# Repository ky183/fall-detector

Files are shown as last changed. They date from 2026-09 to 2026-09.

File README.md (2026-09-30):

# 智能跌倒检测报警器

清华大学第29届硬件设计大赛 · 民生赛道

面向**独居老人**的可穿戴跌倒检测报警器：手腕端采集姿态，腰部融合判断，跌倒时蜂鸣器报警 + OLED 显示 + 按钮取消 + WxPusher 微信推送。

## 当前状态（v0.6 · 2026-09-22，最终版）

- ✅ 全链路闭环（真机实测）：采集 → ESP-NOW(50Hz, ch6) → 三阶段触发 + 随机森林判决 → 报警/取消 → 按需 WiFi + WxPusher 推送
- ✅ v0.6 功能（详见 `docs/handover_2026-09-22_v0.6_ui_push_fix.md`）：
  - **腕端 OLED 产品化**：报警倒计时 / 已推送 / 已取消 / 正常页四级；调试布局由 `DEBUG_DISPLAY` 切换
  - **报警状态回显腰→腕**：`PKT_ACK` 单播，报警全程腕端同步显示
  - **步数统计（腕端纯本地）**：合加速度幅值（SVM）峰值检测 + 连续 4 步确认防误报，RAM 计数
  - **推送文案规范化** + **WiFi 重试卡死修复**（`cannot set config` 根因）+ 推送失败自动扫描诊断
- ⚠️ **两端固件须配套烧录 v0.6**（协议有变更，混搭不崩但腕端弹窗不出现）
- ⚠️ 复现注意事项：腰端供电 ≥6.65V（Micro USB 仅供烧录，否则蜂鸣器声弱）；演示前建议重启手机热点（偶发假死，见交接文档 §3.1）
- 终审答辩已完成（2026-09）

## 系统架构（双板 ESP-NOW）

| 端 | 硬件 | 职责 |
|----|---|---|
| 手腕 | XIAO ESP32S3（自制 PCB）+ MPU6500 + OLED + 按钮 + 电池 | 采集姿态 + 本地步数统计 + 报警回显显示 → ESP-NOW 发送 |
| 腰部 | ESP32-S3 + MPU6500 + 有源蜂鸣器 + EC11 编码器（取消） | 融合判断 + 两段式报警 + WiFi 推送 + 报警状态回传腕端 |

## 目录结构

```
├── firmware/               # 固件源码
│   ├── waist_firmware/     # 腰端固件（ESP32-S3 主控）
│   └── wrist_firmware/     # 腕端固件（XIAO ESP32S3）
├── algo/                   # 算法训练/评估/导出管线（离线，PC 上跑）
│   ├── 01_explore.py       #   随机森林主判决：探索→特征→训练→门限→导出
│   │   ... 05_export.py    #   产物 -> firmware/waist_firmware/rf_model.h
│   ├── sisfall.py          #   SisFall 数据集读取/预处理公共库
│   ├── cnn/                #   CNN 二级仲裁（FallAllD 数据集）
│   │   ├── cnn_train.py    #     训练 + 导出 firmware/.../cnn_weights.h
│   │   ├── host_replay/    #     双语言一致性回放（移植正确性的硬验收）
│   │   └── legacy/         #     接入前的原型（存档，不参与编译）
│   ├── data/               #   数据集（体积大，不入库，各自下载）
│   └── out/                #   训练报告 / 导出副本（留档）
├── docs/                   # 文档
│   ├── plan/               # 规划书、开发计划
│   ├── notes/              # 开发笔记、踩坑记录
│   └── defense/            # 答辩材料
├── hardware/               # 硬件资料
│   ├── schematic/          # 原理图
│   ├── pcb/                # PCB 文件
│   ├── enclosure/          # 3D 打印外壳
│   └── bom/                # 物料清单
├── bin/                    # 烧录文件（编译好的 .bin，交付物）
│   ├── waist/              # 腰端固件烧录文件
│   └── wrist/              # 腕端固件烧录文件
├── tools/                  # 工具脚本
│   └── check_consistency.py#   全项目静态一致性自检（不需硬件/数据集）
├── assets/                 # 演示素材（视频/图片）
└── test/                   # 测试记录
    └── logs/               # 测试日志
```

## 跌倒判定算法（两级判决）

| 级 | 模块 | 训练数据 | 何时跑 | 作用 |
|----|---|---|---|---|
| 第一级 · 主判决 | `fall_detector.cpp` + `rf_model.h` | SisFall 38 人 | 常态 50Hz | 冲击触发 → 特征 → 小随机森林 |
| 第二级 · 二级仲裁 | `cnn_detector.cpp` + `cnn_weights.h` | FallAllD 15 人 | **仅触发后 1 次** | 用腕端 6 通道补判 / 否决 |

- 第一级按"人"留出评估（5 个全新受试者，门限 0.40 部署点）：灵敏度 96.0% / 特异度 98.4%；老年组日常误报 4.6%。四方法完整对比（阈值法/大森林/小森林/混合门控）见 `docs/handover_2026-09-10_algo_v0.3.md` §2.2。
- 第二级只在“已触发 **且** 判定时腕端在线（仲裁窗覆盖率 ≥ `CNN_MIN_COVERAGE`）”时才跑一次；
  腕端离线或覆盖不足则视同不可信，**完全不跑**，行为回退到纯 RF（即已验收的 v2 路径）。
- 角色由 `config.h` 控制：`CNN_ROLE_RESCUE`（补漏报）/ `CNN_ROLE_VETO`（压误报）。
  两者当前均为 0，即影子模式（v0.4，2026-09-11）：CNN 照常推理并记录（decision
  日志的 `cnn p=` 行），但不改变判决结果。原因：CNN 按人评估的真实灵敏度为
  70~78%，低于 RF 主判决的 96%；需积累足够的佩戴对照数据并通过按人划分评估后，
  再决定是否授权其参与判决。
- 腕端链路一断，CNN 直接不跑；RF 主判决不依赖腕端 —— 失效开放（fail-open）设计。

### 改动算法后的验收

改完必跑，三道关都不需要硬件：

```bash
python tools/check_consistency.py       # ① 静态一致性：特征顺序/RF导出保真/板间协议/引脚
python algo/cnn/host_replay/replay.py   # ② 回放：需 g++，含算法保真/部署保真/固件集成（含报警全流程）
algo/05_export.py                       # ③ 随机森林离线指标（需 algo/data/ 数据集）
```

- ① 检查特征顺序、量程标度、两端 `protocol.h` 一致性等 22 项跨文件一致性问题
  （此类问题编译能通过、离线指标也无法暴露），全部通过时退出码为 0。
- ② 把 `firmware/` 下**真实的** `cnn_detector.cpp` / `fall_detector.cpp` /
  `alarm_manager.cpp` 等用 g++ 编到 PC 上跑，与一份独立写的 Python 参考实现
  逐条对比（判别不一致数必须为 0），并验证状态机、仲裁门控与报警全流程。
  数据集不在库时自动跳过「真实窗」项，不影响其余验收。

## 引脚分配

**腰端（ESP32-S3）**

| 功能 | 引脚 | 备注 |
|---|---|---|
| I2C SDA（MPU6500） | GPIO8 | 开漏，需上拉 |
| I2C SCL | GPIO9 | |
| 蜂鸣器（有源模块） | GPIO4 | 高电平=响；模块 VCC→5V；两段式节奏（取消窗内急促哔/推送后长鸣） |
| 按钮1（取消报警） | GPIO5 | 已实现 `PIN_BTN_CANCEL` |
| 按钮2（唤醒/自检） | GPIO6 | **预留**：config.h 尚未定义宏，功能未实现 |

**腕端（XIAO ESP32S3）**

| 功能 | 引脚 | 备注 |
|---|---|---|
| I2C SDA（MPU6500 + OLED） | D4（GPIO5） | 两者共用总线，100kHz |
| I2C SCL | D5（GPIO6） | |
| 交互按钮 | D2（GPIO3） | 短按=交互，长按=主动呼救（触发完整报警链路，联调时兼作模拟跌倒）；`PIN_BTN_1` |
| 电池 | BAT+ / BAT- 焊盘 | 不占 GPIO |

## 环境要求

- Arduino IDE 2.x
- ESP32 board package **3.x**（自带 XIAO_ESP32S3 板型，无需另装 Seeed 包）
- 库：Adafruit_GFX、Adafruit_SSD1306、Adafruit_BusIO、Adafruit_Sensor（MPU 为裸寄存器驱动，无需 MPU 库）

## 快速开始

1. 打开 `firmware/waist_firmware/waist_firmware.ino`，板子选 **ESP32S3 Dev Module**，烧录到腰端。
2. 打开 `firmware/wrist_firmware/wrist_firmware.ino`，板子选 **XIAO_ESP32S3**，烧录到腕端。
3. 串口波特率 `115200`。

## 开发计划

见 `docs/plan/` 与项目规划书（Step 0~7，两周）。

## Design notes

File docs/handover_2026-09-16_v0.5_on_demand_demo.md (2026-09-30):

# 交接文档 v0.5 收尾 —— 按需推送 + 演示/答辩准备（2026-09-16）

> 面向：全体组员（外形/算法/硬件分工均已到位，本文是"当前最后一公里"的交接）
> 前置阅读：`handover_2026-09-14_hw_integration.md`（接线表/交互规则/调参指南，仍然有效）
> 本文新增：①按需推送模式的来龙去脉 ②演示流程脚本 ③答辩要点 ④收尾待办

---

## 1. 本次改动内容（相对 09-14 交接）

### 1.1 推送改为"按需连接"模式（核心改动）

**背景**：常连模式（`PUSH_ALWAYS_ON=1`）下，腰端 WiFi 长期连着热点，射频必须跟随热点信道。
安卓热点会自动选"最空"的 2.4G 信道（1/6/11 三选一），手机不可控地漂移（实测 ch6→ch11）。
每次漂移 = 腰端射频跟着跑 ≠ 腕端 ESP-NOW 固定 ch6 → **腕端数据链路静默断流**（rx 不涨、LED 慢闪）。

**方案**（`config.h` → `PUSH_ALWAYS_ON=0`）：

| 阶段 | 行为 |
|---|---|
| 平时 | 不连 WiFi，腰端常驻 `ESPNOW_CHANNEL=6` 只收腕端包 |
| 报警确认后 | 连热点（超时 10s）→ WxPusher 推送 → 失败重试 6 次×15s |
| 推完/放弃 | `WiFi.disconnect()` + `esp_wifi_set_channel(6)` 跳回，腕端链路无感恢复 |

- **收益**：对任意信道的热点都鲁棒，不再要求信道对齐
- **代价**：微信收到时间 ≈ 7s 取消窗 + ~5s 连接 + ~4s 发送 ≈ **13~18s**（演示时提前打好招呼）
- 推送过程不影响蜂鸣器（已转入"长鸣"阶段持续响）

### 1.2 取消窗 10s → 7s

`ALARM_CANCEL_WINDOW_MS = 7000`。演示节奏更快。
**答辩被问"7 秒够吗"时**：量产定位建议 ≥8s（给老人留反应时间），下限 6s，7s 是演示权衡值（config.h 有注释）。

### 1.3 硬件集成批次（v0.5，commit `36c53e8`，已推送）

- 腕端状态 LED（`hw_led.h/.cpp`，GPIO8）：2s 心跳短闪=正常；1s 慢闪=链路故障（连续 10 次发送失败）；200ms 快闪=MPU 离线
- 腰端有源蜂鸣器两段式：取消窗内急促哔哔（300ms 响/500ms 周期）→ 推送后长鸣（800ms 响/1000ms 周期）
- EC11 编码器替代取消按钮：按压脚接 GPIO5（等效按钮，INPUT_PULLUP），旋转脚悬空
- 实测状态：板间通信 rx 正常涨、lost=0、lastAge 个位数 ms

### 1.4 待提交文件（git 状态截至 2026-09-16）

`36c53e8`（v0.5 硬件集成）已推送；工作区仅剩：
- `firmware/waist_firmware/config.h`（本文 §1.1/§1.2 的参数改动）
- `tools/wifi_test/wifi_test.ino`（调试期填了热点凭据；不想入库可先 `git checkout --` 还原占位符）

---

## 2. 系统现状一句话（答辩自我介绍用）

**腕端 XIAO ESP32S3 自制 PCB（MPU6500 50Hz）→ ESP-NOW 无线 → 腰端 ESP32-S3 大板三阶段触发 + 15 棵随机森林判决 → 两段式蜂鸣本地报警 → 7 秒可取消 → 微信远程推送（WxPusher）。**

### 2.1 核心指标（数据来源：SisFall 公开数据集，留出集按人划分，部署门限 0.40）

| 指标 | 数值 |
|---|---|
| 灵敏度（跌倒检出率） | **96.0%** |
| 特异度（日常活动不误报） | **98.4%** |
| 老年日常误报率 | 4.6% |
| CNN 二级仲裁（影子模式） | 真实灵敏度 70~78%，暂无判决权 |
| 板间链路 | 50Hz，正常时 lost=0 |

### 2.2 工程亮点（可当"创新点"讲）

1. **双传感源融合架构**：腕+腰两个位置独立采集，比单点方案信息量大（腕端否决票 v1 已预留：`ENABLE_WRIST_FUSION`，标定后开启）
2. **RF 主判决 + CNN 二级仲裁的保守架构**：CNN 不抢班夺权（RESCUE/VETO 影子模式跑对照数据），体现"可解释、可回退"的工程决策
3. **按需推送的射频共存设计**：单射频芯片上解决"ESP-NOW 固定信道 vs WiFi 热点信道漂移"的矛盾（§1.1，这是一个真实的工程问题）
4. **两段式报警 + 可取消**：先急促提醒本人（误报可按掉），7s 后才长鸣+推送叫家人——尊重老人尊严，避免"狼来了"
5. **训练域=部署域**：SisFall 200Hz→50Hz 降采样训练，与上板采样率一致；C++/Python 双语言回放 0 不一致

---

## 3. 演示流程脚本（答辩现场用）

**演示前 10 分钟准备**（缺一不可）：
- [ ] 腰端供电：≥6.65V（9V 适配器/PD 诱骗线；**5V 充电宝直连 Type-C 开不了机**）
- [ ] 手机热点开启，**停留在热点设置页面**（vivo"无设备连接自动关热点"高发；设置里关掉该选项更稳）
- [ ] 收推送的手机微信已关注 WxPusher 应用（历史收到过 code=1000 那台）
- [ ] 腕端开机后 LED 2s 心跳闪（若 1s 慢闪=链路故障，先重启腰端）

| 步骤 | 操作 | 观众看到 | 背后发生 |
|---|---|---|---|
| 1 | 双板上电，腰端静置 5s | 腕端 LED 心跳 | baseline 基线采集（`baseline tilt=xx, detector armed`） |
| 2 | 正常走两步、坐下起立 | 什么也不响 | 展示特异度（日常不误报） |
| 3 | **长按腕端按钮 1s**（模拟跌倒） | 蜂鸣器急促哔哔 | 三阶段触发→RF 判决→报警状态机 |
| 4 | **按一下编码器** | 蜂鸣停止 | 误报可取消（7s 取消窗） |
| 5 | 再次长按，这次**不取消** | 哔哔 7s → 转长鸣 | 推送任务连热点发 WxPusher |
| 6 | 举手机 | **微信收到"跌倒报警"** | ~13~18s 到达，提前说明 |
| 7 | （可选）贴串口日志 | rx 涨 lost=0 | 证明链路健康 |

**兜底**：提前录一遍完整流程的视频，现场设备出意外就放视频。

---

## 4. 收尾待办（按优先级）

| 优先级 | 事项 | 说明 |
|---|---|---|
| ★阻塞演示 | 腰端脱离电脑供电方案落地 | ≥6.65V：PD 诱骗线 / 9V 适配器 / 2S 18650 |
| ★阻塞演示 | 全流程彩排 ≥1 次 | §3 脚本跑通，掐表演述词 |
| ★阻塞演示 | 提交剩余改动并推送 | §1.4 两个文件 |
| 加分 | 佩戴测试协议 A/B + 调参 | 按 09-14 文档 §5，攒 decision 日志微调 `FD_RF_THRESHOLD` |
| 加分 | OLED 换新到货插 H1 座 | 当前模块烧毁，非阻塞（init FAIL 为预期） |
| 加分 | 腕端电池续航 ≥1h 验证 | 演示时长足够即可 |
| 加分 | 腰端洞洞板集成+腰包 | 消灭杜邦线，观感分 |
| 答辩材料 | PPT / 演示视频备份 | 建议含：系统架构图、指标表（§2.1）、双板实物照 |

---

## 5. 答辩 Q&A 备查

- **为什么用随机森林不用神经网络？** RF 在我们的数据上灵敏度 96% 显著优于 CNN v2 的 70~78%，且可解释、C++ 部署简单、推理开销可忽略。CNN 保留为二级仲裁（影子模式），攒数据后再授权——这是数据驱动的选择，不是能力问题。
- **数据集哪来的？** SisFall 公开数据集（含真跌倒+老年日常），按人划分防泄漏；200→50Hz 降采样保证训练域=部署域。
- **误报怎么办？** 三道防线：①特异度 98.4% ②7s 取消窗 ③腕端否决票（预留）。
- **老人没带手机 / 没网怎么办？** 本地蜂鸣器独立于网络；推送只是增项。
- **隐私？** 全部计算在设备端（边缘计算），不上云、不传原始数据，只发一条报警文本。
- **为什么双板？** 腰部姿态信息量大（跌倒=冲击+姿态剧变），腕部补充手臂动作；单点方案二者只能得其一。
- **信道漂移怎么解决的？** 见 §1.1，按需连接模式（实测发现热点漂移问题后采用的方案）。

---

## 6. 已知坑速查（现场应急）

| 症状 | 原因 | 处置 |
|---|---|---|
| 推送时 `WiFi connect timeout` | 热点被手机自动关了 / 手机连着别的 WiFi | 停留在热点设置页；关 WiFi 只留热点 |
| 腕端 LED 1s 慢闪 | 链路故障 | 重启腰端（信道被占/漂移残留） |
| 腰端 Type-C 供电不启动 | 电压 <6.65V | 换 ≥6.65V 供电 |
| 腕端插电池不亮 | （已修）BAT 飞线已补焊，SW2 已 P4 锡桥旁路 | 插电池=开机，无需开关 |
| OLED 不亮 | 模块烧毁待换 | 不影响主链路，忽略 |
| 烧录不上（腰端） | 用错 Type-C 当烧录口 | 烧录用 **Micro USB**（CH340） |

---

*文档生成：2026-09-16，随 v0.5 收尾批次维护。*

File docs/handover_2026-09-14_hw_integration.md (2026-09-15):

# 硬件集成交接文档 v0.5（2026-09-14）

> 写给组员（调参 / 外形设计 / 后续接手者）：硬件框架已全部打通并验收，
> 本文是**接线位置、交互规则、调参入口**的唯一速查。看完即可动手，不必考古聊天记录。
> 配套：算法细节见 `handover_2026-09-10_algo_v0.3.md`（RF 主判决）与
> `handover_2026-09-11_cnn_v2.md`（CNN 影子模式）。

## 0. 一句话状态

双板全链路（采集 → ESP-NOW → 三阶段触发 + 随机森林判决 → 蜂鸣器两段式报警
→ 编码器取消 → WiFi 常连 → 微信推送）已在实物上验收通过；
剩余工作集中在**跌倒判定参数调优**（本档 §5）与外壳/佩戴形态。

## 1. 系统总览

```
腕端 XIAO ESP32S3（自制PCB）          腰端 ESP32-S3 大板（面包板/杜邦线）
  MPU6500#1 + 按钮 + LED + 电池         MPU6500#2 + 有源蜂鸣器 + EC11编码器
  （OLED 座已留，屏坏待换）             + WiFi 常连 → WxPusher 微信推送
        └────── ESP-NOW 50Hz ch6 ──────┘   （信道必须=热点信道，见 §7）
```

## 2. 接线速查表（★ = 外形设计可挪，见 §6）

### 2.1 腕端（自制 PCB，引脚由 PCB 走线决定，**不可软件改位**）

| 功能 | 位号 | 丝印 | GPIO | 可否挪 |
|---|---|---|---|---|
| I2C SDA（MPU+OLED） | — | D4 | 5 | ❌ PCB 定死 |
| I2C SCL | — | D5 | 6 | ❌ |
| 按钮 SW3 / 外接口 P3 | SW3 | D2 | 3 | ❌ |
| 状态 LED1 | LED1 | D9 | 8 | ❌ |
| OLED 座（屏待换） | H1 | — | I2C | ❌ |
| 电池链路 | U12→SW2→P5→飞线→XIAO底面BAT焊盘 | — | — | ❌ |
| 空闲扩展脚 | 排母 | D0/D3/D7/D8 | 1/4/44/7 | ✅ 可接新外设 |

### 2.2 腰端（大板 H4 排针，杜邦线连接，**随时可挪**）

| 功能 | 大板脚 | GPIO | 模块侧 |
|---|---|---|---|
| MPU#2 SDA ★ | H4 第12脚 | 8 | SDA |
| MPU#2 SCL ★ | H4 第15脚 | 9 | SCL |
| MPU#2 电源 ★ | 3V3 / GND | — | VCC / GND |
| 蜂鸣器 I/O ★ | H4 第4脚 | 4 | I/O（高电平响） |
| 蜂鸣器电源 ★ | 3V3（或5V）/ GND | — | VCC / GND（宽压3.3~5V） |
| 编码器按压脚 ★ | H4 第5脚 | 5 | 两脚无方向（按压导通） |
| 编码器另一脚 ★ | GND | — | 旋转脚 A/B/COM 全悬空 |
| 烧录+供电 | Micro USB（CH340口） | — | 电脑（板选见 §8） |

## 3. 交互规则（谁按什么发生什么）

| 操作 | 位置 | 效果 |
|---|---|---|
| **长按 1 秒** | 腕端按钮 SW3 | 模拟跌倒（联调专用）：腰端直接触发报警流程 |
| 短按 | 腕端按钮 | 预留交互（OLED 翻页 TODO，现无动作） |
| **按压一下** | 腰端编码器 | **取消报警**并复位系统（仅报警态有效） |

**报警状态机**（触发后自动流转，10s / 推送两个节点）：

```
触发(真摔或长按模拟)
  → [0~10s 取消窗] 蜂鸣器急促哔哔(0.3响/0.2停) —— 按编码器 → 全停+复位
  → [10s 到] 自动连WiFi推送微信 → 蜂鸣器转长鸣(0.8响/0.2停) —— 按编码器 → 停+复位
  → 复位后需站直5s重新采基线（串口 detector armed）
```

**腕端 LED 闪法**：每2s短闪=一切正常；每秒闪=链路故障(腰端没开/信道不对)；
快速闪=MPU 离线。

**使用纪律（不是 bug，摘戴会伪触发）**：先佩戴→再上电；关机→再摘下；
MPU 板面平贴腰前。

## 4. 串口日志速查（调参看什么）

- `[STAT] rx=N lost=N lastAge=Nms`：链路健康，lost 涨=丢包
- `[DETC] decision proba=0.47 peak=78.5 tilt=1deg gyr=500 wrist=11.2/cov98% (3501ms)`：
  **核心行**。proba≥0.4 判跌倒报警；wrist/cov=腕端数据健康度
- `cnn p=0.xx`：CNN 影子记录（**不参与判决**，攒对照数据用，勿据此调参）
- `detector armed`：基线完成，开始判定

## 5. 调参指南（唯一需要动的文件：`waist_firmware/config.h`）

| 参数 | 现值 | 方向 | 效果 |
|---|---|---|---|
| `FD_TRIGGER_SVM` | 30 m/s² | ↓更易触发 | 冲击门限（≈3.1g） |
| `FD_TRIGGER_GYR` | 200 °/s | ↓更易触发 | 旋转门限（与SVM满足其一） |
| `FD_RF_THRESHOLD` | 0.40 | ↓更灵敏、误报升 | **判决门限，主调项**（0.3/0.4/0.5 档见算法交接文档 §2.2） |
| `FD_BASELINE_MS` | 5000 | 一般不动 | 开机站姿基线时长 |
| `FD_COLLECT_MS` | 3500 | 一般不动 | 触发后确认窗 |
| `ALARM_CANCEL_WINDOW_MS` | 10000 | 不建议<6000 | 取消窗 |

**调参方法**：改宏 → 烧腰端 → 按下表协议做动作 → 存档所有 decision 行：

- 协议 A（阴性，要求零报警）：走30s / 快坐×3 / 跳×3 / 弯腰×3 / 下蹲×3
- 协议 B（阳性，要求≥7/9 报警）：垫上侧摔/前扑/后倒各×3，每轮取消后站直5s

误报多 → `FD_RF_THRESHOLD` 上调；漏检多 → 下调 SVM/阈值。改完记录在
`test/logs/`（文件名建议 `param_<日期>_<阈值>.txt`）。

## 6. 外形设计者：改 GPIO 位置的规则

- **腰端随便挪**：杜邦线换到别的 GPIO + 改 `waist_firmware/config.h` 对应宏
  （`PIN_I2C_SDA/SCL/PIN_BUZZER/PIN_BTN_CANCEL`）→ 重烧即生效。
  唯一注意：I2C 两根建议用默认 I2C 脚（8/9），其他脚需软件 Wire 兼容。
- **腕端不能挪**：引脚由 PCB 走线焊死，挪=飞线。需要新传感器/外设时
  用 §2.1 的空闲扩展脚（D0/D3/D7/D8），固件里加宏即可。
- 外壳开孔参考 `腕端PCB交接文档_v1.md` §8（USB-C/OLED窗/SW3/SW2/表带通道）。
  腰端建议腰包方案（蜂鸣器出声、编码器可按、USB 可插）。

## 7. 已知事项与坑（2026-09-14 快照）

1. **OLED 模块已损坏**（PCB 首插疑似错位烧毁），已购新待换；
   无屏不影响任何功能，`OLED init FAIL` 日志为预期
2. **腕端 SW2 电源开关虚焊失效**，已用 P4 焊盘锡桥旁路：
   插电池=开机，拔电池=关机；充电照常（USB 插线）
3. **腰端供电**：桌面调试 Micro USB 即可；**脱离电脑演示必须 ≥6.65V**
   （PD 诱骗线/9V 适配器/2S 电池），5V 充电宝带不动 WiFi
4. **热点信道约束**：手机热点须 2.4G 且实际信道=6（=ESPNOW_CHANNEL）；
   失配串口有 `!!` 告警。换热点先看 `WiFi connected ... ch=X`
5. 推送期间 ESP-NOW 丢包短暂暴涨属正常（WiFi 借射频），推完自恢复
6. `secrets.h` 不入库：新环境复制 `secrets.h.example` 填 WiFi/WxPusher

## 8. 烧录速查

| 端 | 板型 | 关键选项 | 口 |
|---|---|---|---|
| 腰端 | ESP32S3 Dev Module | USB CDC on Boot=**Disabled** | Micro USB |
| 腕端 | XIAO_ESP32S3 | 默认 | 板载 Type-C |

串口均 115200。改任何算法相关文件后跑 `python tools/check_consistency.py`（22 项自检）。

---
*本档对应提交：v0.5 硬件集成。文档与代码同库，发现不符以代码为准并更新本档。*

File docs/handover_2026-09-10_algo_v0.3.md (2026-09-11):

# 交接文档 — 2026-09-10 · 算法上板 v0.3

> 写给后续开发者（人或 AI）：本文档记录截至 2026-09-10 晚的项目全貌。
> 阅读顺序建议：§1 现状 → §3 已验证/未验证 → §4 当前阻塞 → §6 待办。
> 代码内的权威注释：`fall_detector.cpp` 头部有"训练↔固件对应关系表"，改任何一侧先看它。

## 0. 一句话状态

跌倒判定算法已完成"离线训练 → C++ 移植 → 上板运行 → 微信推送"全链路；
腰端已在真机上跑通判定与推送；**当前阻塞在硬件层（供电 ≥6.65V 未落实）**，
佩戴测试与腕端融合标定未开始。

## 1. 系统当前形态

```
腕端 XIAO ESP32S3 ──ESP-NOW 50Hz ch6──> 腰端 ESP32-S3 大板
  MPU6500(±8g/±500°/s)                   MPU6500#2 + 蜂鸣器 + 取消按钮 + WiFi
  OLED + 按钮(长按=模拟跌倒)              ├ 三阶段触发 + 15树随机森林判定
  （腕端只发原始数据，不做判定）           ├ 报警状态机(10s取消窗) → WxPusher微信
                                         └ WiFi常连模式(与ESP-NOW同信道共存)
```

| 模块 | 状态 | 说明 |
|---|---|---|
| 双板采集 + ESP-NOW | ✅ 稳定 | 常连共存下丢包 ~7%，lastAge 稳定个位数 ms |
| 腰端判定算法 | ✅ 已上板 | 详见 §2 |
| 报警/取消/推送 | ✅ 实测通过 | 摔倒→微信 ~17s（3.5s判定+10s取消窗+4s POST）|
| 腕端融合 v1 | ⚠️ 代码就绪未验证 | `ENABLE_WRIST_FUSION=0`，等待腕端链路+自采数据标定 |
| 佩戴测试 | ❌ 未开始 | 弹力腰带未到货 |
| 供电 | ❌ **阻塞** | 大板需 ≥6.65V，详见 §4 |

## 2. 算法部分（algo/ 目录）

### 2.1 数据集与管线

- 数据集：**SisFall**（38 人 / 4505 文件 / 1798 次跌倒，腰部佩戴，200Hz）
  - 下载位置：`algo/data/sisfall/`（gitignore，组员自行下载）
  - 下载方式：HuggingFace 镜像 `hf-mirror.com/datasets/Trupal7/Sisfall_Dataset`
    （直连 hf.co 被墙；zip 232MB，解压后即 SisFall_dataset 目录）
- 管线脚本（按序号执行，各带 `check` 自检模式）：
  1. `sisfall.py` — 加载器：位值→物理单位、200→50Hz 块平均降采样（=固件采样率，
     训练域=部署域）、姿态角（低通 IIR α=0.03，与固件同参）
  2. `01_explore.py` — 可视化证明"三阶段判决缺一不可"（答辩素材 `out/explore.png`）
  3. `02_features.py` — **触发锚定**特征提取（不是全文件滑窗，防泄漏），12 特征，
     5920 样本。v2 关键点：**量程裁剪 CLIP_ACC=±8g / CLIP_GYR=±500°/s**（数据集
     传感器 ±16g/±2000°/s，不裁剪则模型学到硬件达不到的规则，上板失效）
  4. `03_train.py` — 训练+严格评估（见 2.2）
  5. `04_threshold.py` — 阈值基线 + 四方法对比 + 参数标定（只在训练集标定）
  6. `05_export.py` — 训练 15树小森林 → 生成 `firmware/waist_firmware/rf_model.h`
     （自动生成勿手改）+ **双语言一致性回放**（C 遍历逻辑的 Python 镜像 vs sklearn，
     5920 样本判决 0 不一致才允许上板）

### 2.2 关键指标（答辩数字，全部来自"模型没见过的人"）

| 方法 | 留出集灵敏 | 留出集特异 | 老年日常误报 | SE06老人真摔检出 |
|---|---|---|---|---|
| 阈值法（三阶段AND） | 72.8% | 99.3% | 3.8% | 76.0% |
| 随机森林 300 树 | 97.9% | 97.9% | 6.7% | 88.0% |
| **小随机森林 15树×深6（上板方案）** | **97.1%** | **97.5%** | 6.9% | 89.3% |
| 小森林@门限0.4（部署点） | 96.0% | 98.4% | 4.6% | 85.3% |

- 评估方法论（答辩重点）：按"人"划分（SA04/09/14/19/23 留出）；老年组不进训练、
  专门做泛化压力测试；阈值参数只在训练集标定后冻结
- 已知弱点（诚实记录）：坐姿晕倒型跌倒（F13/F14/F15）漏报集中；体重最轻受试者
  的"软摔"漏报；改进思路是自适应基线，评估为高风险暂缓

### 2.3 上板实现（腰端固件）

- `fall_detector.cpp`：状态机 BASELINE(开机站5s采基线)→IDLE(触发: SVM>30 或
  |ω|>200)→COLLECT(3.5s确认窗)→判决→LATCHED(锁存到报警取消)。特征窗口定义
  与训练侧逐条对应（注释里有对照表）
- `rf_model.h`：1083 节点 ≈17KB 常量，15 树遍历
- 判决日志格式：
  `[DETC] decision proba=0.47 peak=78.5 tilt=1deg gyr=500 wrist=11.2/cov98% (3501ms)`
  （wrist 字段无论融合开关都输出，是标定融合阈值的数据来源）

## 3. 已验证 vs 未验证（接手必读）

**已在真机验证：**
- 判定→报警→取消→微信推送全链路（多次，含 code=1000 成功回执）
- WiFi 常连 + ESP-NOW 同信道共存（POST 期间 rx 仍增长）
- 判定管线"正确拒绝"能力（强冲击+无姿态变化 → proba=0.07 拒绝）

**未验证（下次继续的点）：**
1. **腕端数据进判决日志**：实测时腕端链路已死，`wrist=-1.0/cov0%`。
   验证标准：腕端开机+链路正常时，decision 行出现 `wrist=9~12/cov>90%`
2. 佩戴状态下的完整测试协议（A 阴性/B 阳性，见下）
3. 融合否决票的实际效果（阈值是工程初值，需自采数据标定）

## 4. 当前头号问题：供电（未解决，其他问题的疑似总根源）

**大板输入必须 ≥6.65V**（板载 DC-DC 最小输入；5V 充电宝实测带不动 WiFi）。
2026-09-10 晚出现的一组症状统一指向供电不稳：
- 无人触碰时 SVM 恒 ~41 m/s²（4.2g 假读数）反复触发
- MPU 反复 offline（时间点与 WiFi 活动窗重合）
- WiFi 连接失败、腕端链路大量丢包

**待办**：PD 诱骗线（充电宝→9V→DC5521，10~20元）或 9V/12V DC 适配器。
换正规供电后第一步：静置观察 SVM 是否回到 ~9.8、trigger 风暴是否消失。
（腕端 XIAO 无此问题，5V USB 正常。）

## 5. 已知设计内行为与使用纪律（不是 bug，答辩可能被问）

1. **摘戴/摆弄装置 = 伪跌倒信号**（姿态大变+静止）。纪律：先佩戴→再上电；
   先关机→再摘下。误触发有 10s 取消窗兜底。腕端否决票正式启用后可拦大部分
2. **MPU 朝向**：绝对朝向无所谓（基线相对），但推荐板面平贴腰前（与 SisFall
   训练一致）。上电后改变朝向会被视为跌倒
3. **基线假设开机站立**：报警取消后会重新采基线，需站直 5 秒等 `detector armed`
4. 推送时间线 ~17s，可调 `ALARM_CANCEL_WINDOW_MS`（不建议低于 6s）

## 6. 待办清单（优先级）

1. 【阻塞】解决供电（PD 诱骗线/适配器）→ 复测 SVM 稳定性
2. MPU 四焊点补焊（VCC/GND/SDA/SCL）+ 杜邦线固定（佩戴装备到货前的常规加固）
3. 腕端链路验证（§3.1 的标准）
4. 佩戴装备到货 → 测试协议：
   - A 阴性：走30s/快坐×3/跳×3/弯腰×3/下蹲×3，合格=零报警（decision proba<0.4 允许）
   - B 阳性：垫上侧摔/前扑/后倒 ×3，合格=≥7/9 报警；每轮取消后站直5s
   - 记录所有 decision 行（proba + wrist 值）= 第一批自采标定数据
5. 用自采数据标定融合阈值 → `ENABLE_WRIST_FUSION=1`
6. 数据采集工具（腕腰两端 DEBUG_DATA CSV 输出）→ 域差距量化
7. （可选）"自愈检测"创新点、第二数据集交叉验证、起跳类特征增强

## 7. 新环境复现指南（组员从零跑通）

```powershell
git clone https://github.com/ky183/fall-detector.git
cd fall-detector
# 数据集（232MB，需 Python: numpy/pandas/scipy/matplotlib/scikit-learn）
#   从 hf-mirror.com/datasets/Trupal7/Sisfall_Dataset 下载 zip
#   解压到 algo/data/sisfall/SisFall_dataset
python algo\02_features.py check     # 自检
python algo\02_features.py all       # 全量特征（~2分钟）
python algo\03_train.py              # 训练+评估报告
python algo\05_export.py             # 重新生成 rf_model.h + 一致性回放
# 固件：Arduino IDE 打开 firmware/waist_firmware（板: ESP32S3 Dev Module,
#   USB CDC on Boot=Disabled, 烧录口 Micro USB），secrets.h 照
#   secrets.h.example 填。腰端供电必须 ≥6.65V！
```

## 8. 关键参数速查（全部在腰端 config.h，有注释）

| 参数 | 值 | 含义 |
|---|---|---|
| ESPNOW_CHANNEL | 6 | 两端一致；常连模式下还须=热点信道（失配有串口告警）|
| FD_TRIGGER_SVM / GYR | 30 m/s² / 200°/s | 冲击触发（满足其一）|
| FD_RF_THRESHOLD | 0.40 | 森林判决门限（部署点指标见 §2.2）|
| FD_BASELINE_MS / COLLECT_MS | 5000 / 3500 | 基线时长 / 确认窗时长 |
| ENABLE_WRIST_FUSION | 0 | 腕端否决票（标定后开）|
| FUSION_VETO_* | 0.6 / 30 / 12 | 覆盖率/腰端强冲击/腕端安静阈值 |
| PUSH_ALWAYS_ON | 1 | WiFi 常连模式（0=按需连接）|
| PUSH_MAX_ATTEMPTS | 6 | 推送重试 6 次×15s，不再丢弃 |
| ALARM_CANCEL_WINDOW_MS | 10000 | 报警取消窗 |

## 9. 文件索引

| 路径 | 内容 |
|---|---|
| `algo/` | 离线管线（§2.1），`data/`和`reference/`已gitignore |
| `firmware/waist_firmware/rf_model.h` | 森林常量表（05_export.py 生成）|
| `firmware/waist_firmware/fall_detector.*` | 判定算法（头注释=对应关系表）|
| `firmware/waist_firmware/net_pusher.cpp` | 推送（常连/按需双模式）|
| `algo/out/train_report.txt` | 训练评估报告留档 |
| `tools/` | i2c_scanner / btn_test / wifi_test 排障工具 |
| `docs/notes/mpu6500_driver_note.md` | MPU6500 驱动踩坑记录 |

---
*v0.3 tag：`git tag -a v0.3`（若提交时遗漏）。文档随代码一起 commit。*

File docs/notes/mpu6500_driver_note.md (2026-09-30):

# 踩坑记录：MPU 模块实为 MPU6500，更换裸寄存器驱动

> 日期：2026-09-06 · 记录人：组长 · 影响范围：腕端/腰端传感器层

## 现象

- 腕端固件持续打印 `[SENS] MPU offline, retrying...`，SVM 显示 0
- I2C 扫描器能扫到 0x68（器件"在线"）
- Adafruit_MPU6050 库的 `begin()` 始终失败

## 排查过程（供复用）

1. I2C 扫描器确认器件地址在线 → 排除接线问题
2. 换第二个模块、换杜邦线、量上拉电压（SDA 对 GND ≈3.3V）→ 排除硬件损坏
3. 加诊断日志直接读 WHO_AM_I 寄存器（0x75）→ **读出 0x70**
4. 结论：模块实际是 **MPU6500**（WHO_AM_I=0x70），而非 MPU6050（0x68）
5. Adafruit_MPU6050 库严格校验芯片 ID=0x68，故拒绝初始化——这就是
   "扫描器通、固件不通"的根因

期间还发现并修复了另外两个独立问题（同一次排障中）：

- XIAO 排针焊点虚焊（D5 对 GND 电压异常，补焊解决）
- I2C 400kHz 时钟在补焊总线上不稳（降回默认 100kHz，50Hz 采样带宽足够）

## 解决方案

`firmware/wrist_firmware/sensor_manager.cpp` 改为**裸寄存器驱动**：

- 直接读写 MPU 寄存器（唤醒 0x6B、量程 0x1B/0x1C、滤波 0x1A、数据 0x3B 连读 14 字节）
- 芯片 ID 宽容校验：接受 0x68/0x70/0x71 等（6050/6500/6515 全系）
- 不再依赖 Adafruit_MPU6050 库（该库其他功能仍在，只是本驱动不使用）
- 腰端 MPU 驱动直接复用这份实现

## MPU6500 vs MPU6050 性能影响

| 项 | MPU6050 | MPU6500 | 对本项目影响 |
|----|---|---|---|
| 加速度计 | 16bit，同类设计 | 基本相同 | 无 |
| 陀螺仪噪声 | 0.005 °/s/√Hz | ≈0.0037 °/s/√Hz | 6500 略优 |
| 量程/分辨率/采样率 | 16bit，±2~16g | 相同配置可用 | 无 |
| 寄存器/数据格式 | 基准 | 兼容 | 无（裸驱动已验证） |

**结论：对跌倒检测（SVM 阈值 + 角速度特征）无实质影响，陀螺噪声甚至略低。**
算法组按原计划标定即可，无需针对型号调整。本问题可作为"问题定位与解决"的案例引用。

## 经验

1. 廉价 GY 系模块芯片型号与商品名不符很常见，遇"库不识别"先读 WHO_AM_I
2. I2C 排障顺序：扫描器（地址在不在）→ 读 ID（芯片是什么）→ 时序（降速试）
3. 自焊开发板排针必须逐点测通断，"灯亮"只代表供电脚焊好了

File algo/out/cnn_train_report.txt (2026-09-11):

================================================================
CNN 二级仲裁 v2 训练报告（smoke=False, seed=42, epochs=50）
划分: 按受试者留出 ['1', '14', '5']；标签: 峰值锚定；增广: rot=0.5 drop=0.25 mask=0.25
================================================================

---- 模型 A：随机旋转增广（默认导出版） ----
 thr   TP   FN   FP   TN    sens    spec
 0.5   29   11    4 1042   0.725   0.996
 0.6   29   11    4 1042   0.725   0.996
 0.7   28   12    3 1043   0.700   0.997
 0.8   27   13    2 1044   0.675   0.998
 0.9   26   14    2 1044   0.650   0.998
逐人（thr=0.8）:
  1: sens=0.789 spec=1.000 (TP15 FN4 FP0 TN302)
  14: sens=0.000 spec=1.000 (TP0 FN0 FP0 TN351)
  5: sens=0.571 spec=0.995 (TP12 FN9 FP2 TN391)
腕端30%丢包鲁棒性(thr=0.8): sens=0.700 spec=0.992

---- 模型 B：无旋转增广（ablation 对照） ----
 thr   TP   FN   FP   TN    sens    spec
 0.5   31    9    9 1037   0.775   0.991
 0.6   31    9    9 1037   0.775   0.991
 0.7   31    9    8 1038   0.775   0.992
 0.8   31    9    8 1038   0.775   0.992
 0.9   31    9    7 1039   0.775   0.993
逐人（thr=0.8）:
  1: sens=0.842 spec=0.993 (TP16 FN3 FP2 TN300)
  14: sens=0.000 spec=0.997 (TP0 FN0 FP1 TN350)
  5: sens=0.714 spec=0.987 (TP15 FN6 FP5 TN388)
腕端30%丢包鲁棒性(thr=0.8): sens=0.900 spec=0.990

判读：A 对 B 若 sens/spec 均无明显下降，则旋转增广换来佩戴朝向鲁棒性是纯收益；若明显下降，重新评估旋转策略（如限幅小角度）后再定导出版。

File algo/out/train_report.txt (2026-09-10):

== 留出集（5 个全新青年受试者） ==
   灵敏度 Sensitivity =  95.5%  (358/375 跌倒被检出)
   特异度 Specificity =  99.9%  (误报 1/682)
   精确率 Precision   =  99.7%

== 误报的动作明细（top） ==
   D11: 1/25 次误判

== 漏报的跌倒明细 ==
act subject trial
F13    SA04   R02
F13    SA09   R02
F15    SA09   R01
F15    SA09   R03
F01    SA14   R02
F06    SA14   R03
F09    SA14   R05
F05    SA23   R01
F05    SA23   R02
F05    SA23   R03
F05    SA23   R04
F05    SA23   R05
F13    SA23   R01
F13    SA23   R03
F15    SA23   R02
F15    SA23   R03
F15    SA23   R04

== 特征重要度（应与物理直觉一致） ==
   gmag_peak_imp    0.272 ###########################
   svm_peak_imp     0.206 ####################
   svm_impulse_imp  0.132 #############
   dtilt_med_post   0.105 ##########
   svm_std_post     0.062 ######
   dtilt_max_post   0.061 ######
   dtilt_chg        0.045 ####
   svm_dip_pre      0.036 ###
   svm_mean_pre     0.023 ##
   gmag_std_post    0.022 ##
   dip_dur_pre      0.022 ##
   svm_mean_post    0.016 #

== 老年组压力测试（训练只见青年，测老人日常动作） ==
   老年日常误报 29/951 = 3.0%（SisFall 论文预期：明显差于青年，属正常现象）
   D11: 11 次
   D08: 9 次
   D14: 5 次
   D10: 2 次
   D17: 1 次
   SE06(柔道专家)真实跌倒检出 62/75 —— 老人跌倒能否检出，比误报更关键

== 5 折按人交叉验证（训练集内部，看稳定性） ==
   Sensitivity 97.3% ± 1.6
   Specificity 98.0% ± 0.7

== 判决门限 sweep（灵敏度 vs 特异度 trade-off） ==
      th   sens%   spec%
     0.3    97.9    97.9
     0.4    97.1    98.8
     0.5    95.5    99.9
     0.6    92.8    99.9
     0.7    89.1    99.9
   （部署原则：宁可灵敏，误报有人工取消窗口兜底）

========== 04_threshold 追加 ==========
== 阈值参数（仅用训练集标定，已冻结） ==
   T1 冲击峰值    > 30 m/s²  (3.1g)
   T2 角速度峰值  > 200 °/s
   T3 姿态变化    > 20 °
   T4 冲击后活动  < 6 m/s²
   训练集得分 (SE+SP)/2 = 86.4%

== 四种方法对比（留出集=5 个全新青年受试者） ==
   方法                灵敏%    特异%   误报    老年FP%   SE06检%
   A 阈值法            72.8   99.3    5      3.8     76.0
   B 随机森林300        97.9   97.9   14      6.7     88.0
   C 小随机森林15x6      97.1   97.5   17      6.9     89.3
   D 混合门控           96.0   97.9   14      6.6     82.7

决策依据（第⑥步 C++ 移植选型）：
    - 若 C 小森林 ≈ B 大森林 -> 用 C（数组化移植体积可控）
    - 若 C 明显掉点且 D 占优 -> 上板走 D（阈值粗筛 + 精简 ML）
    - 阈值法 A 是保底与参照系，也是"两代方法对比"报告章节的数据来源

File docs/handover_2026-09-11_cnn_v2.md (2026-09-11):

# CNN 二级仲裁 v2 交接文档（v0.4，2026-09-11）

> 写给算法组：本文说明对 CNN 二级仲裁（commit `e23f5d5`，下称 v1）的审阅结论、
> 本轮全部改动、理由与验证结果。改动仅涉及**训练侧与一个固件开关**，
> 你的板端实现（cnn_detector.cpp / cnn_detector.h / host_replay）一行未动。
> 复核指引见 §8，全部结论可用仓库内工具一键复现。

## 0. 一句话摘要

v1 的板端移植质量过硬（双语言回放 0 不一致），但训练侧有三处方法论问题
（窗口泄漏 / trial 级标签 / 无域增广），导致其指标虚高、且不可直接部署。
本轮重写训练脚本（v2）并以**影子模式**上板：RF 仍独自主判，CNN 只记录
不生效，等佩戴测试攒够对照数据后再决定是否授权。

## 1. 对 v1 的审阅结论（已当面/文档反馈过，此处留档）

**保留不动的部分**（这些做得很好）：
- 腰腕 12 通道输入设计与"二级仲裁只看腕端增量信息"的定位
- 归一化换算链（LSB 往返）与文件头文档 —— 实测量化过错法代价，可信
- 全部工作缓冲 static 化（避开 18KB 栈溢出）
- host_replay 三层验收 + check_consistency 静态自检 —— 本轮全部复用

**发现的问题**（均为训练侧，板端无 bug）：
1. 随机窗口划分：50% 重叠的相邻窗口横跨训练/测试两侧 -> 指标虚高
2. trial 级标签：摔前站立、摔后躺卧的窗口也被标为"跌倒" -> 错误语义
3. 无部署域增广：训练数据腕端从不缺失、轴向固定，与实机（丢包 + 佩戴
   朝向不可控）存在两个未对齐的域差

## 2. 改动清单与理由

### 2.1 firmware/waist_firmware/config.h —— 影子模式（1 行）

`CNN_ROLE_RESCUE` 1 -> 0。

- **影响**：CNN 照常计算并记录（decision 日志的 `cnn p=` 行不变），
  但不再能把 RF 未判跌倒的事件补判为报警。行为回退到纯 RF（= 已验证的 v2 主判决）。
- **理由**：v2 重训后的真实灵敏度约 70~78%（RF 为 96%），在"RF 漏掉的
  子集"上的表现未测过，不应有改变判决的权力。
- **开启条件**：佩戴测试攒出"RF 对/错 × CNN p 高/低"对照表且分布达标后。

### 2.2 algo/cnn/cnn_train.py —— 重写为 v2

| 修复 | 实现 | 理由 |
|---|---|---|
| 按受试者划分 | 每 5 人留出 1 人（本次 1/5/14），jitter 副本只进训练侧 | 消除窗口泄漏，测试集全是训练没见过的人 |
| 峰值锚定标签 | 正样本=腰端 SVM 峰值居中 2s 窗（与板端 cnn_detector_prob 取窗同构）；摔前(-6,-4s)/摔后(+4,+6s)补负样本 | 标签语义改为"窗口内正在跌倒"，且训练/部署取窗方式一致 |
| 腕端缺失增广 | 25% 整窗置 0 + 25% 随机 30% 拍置 0 | 板端 cov<1 的窗口里有 0 值，原属域外输入 |
| 随机旋转增广 | 腰/腕各自独立随机 SO(3)，同端 acc/gyr 同一旋转矩阵（保手性） | 腕端 PCB 佩戴朝向不可控 + 数据集轴向无从核对，迫使模型学朝向无关特征 |
| ablation | 旋转开/关各训一版对比，导出旋转版 | 项目纪律：不让性能无谓变差，用数据取舍 |

归一化常量与导出格式与 v1 逐字一致，**板端无需任何改动**。
新增 `--smoke`（合成数据验流程）、`--no-rot`、`--epochs` 参数。

### 2.3 firmware/waist_firmware/cnn_weights.h —— 重新导出

v2 旋转增广版权重（6210 float，规模不变）。由 2.2 的脚本自动生成。

### 2.4 新增 algo/cnn/inspect_data.py —— 数据体检工具

训练前的数据可信度检查（标度 / SMOTE 痕迹 / 腕陀螺来源 / 零填充），
答辩复现用。本次对 FallAllD 处理版 pkl 的体检结论见 §3。

## 3. 数据体检结论（FallAllD_40SamplesPerSec_ActivityIdsFiltered.pkl）

来源核实为 Kaggle "Derived FallAllD Dataset"（CC0）。四个关键结论：

1. **标度精确成立**：腰端静止段 |acc| 中位数换算后 = 1.00g（50 分位），
   证实 4096 LSB/g 假设；与板端 ±8g/±500dps 换算链完全对齐
2. **腕端陀螺是真实独立通道**（与腰部相关系数仅 0.19，非复制非填充）
3. **未发现 SMOTE 合成样本**（索引连续、无重复键）——Kaggle 数据卡片
   声明的 SMOTE 只在上传者自己的 notebook 里，未写入 pkl
4. trial 统一 800 点（20s）为截断而非填充（尾部零值占比 0%）

结论：该 pkl 可直接用于训练；原始版 FallAllD.pkl（462MB）留作后备。

## 4. v2 训练结果（真实、无泄漏）

数据：3875 窗（正 370 / 负 3505），留出受试者 1/5/14，seed=42，50 epochs。
完整报告见 `algo/out/cnn_train_report.txt`。

| 测试条件 | A 旋转增广（已导出） | B 无旋转（对照） |
|---|---|---|
| 原始轴向 | sens 67.5% / spec 99.8% | sens 70.0% / spec 98.8% |
| **随机旋转（模拟腕端乱戴）** | **sens 77.5% / spec 98.7%** | sens 92.5% / **spec 77.7%（崩）** |
| 旋转 + 30% 丢包 | sens 77.5% / spec 97.8% | spec 74.1%（崩） |

- B 的 sens 升高是"整体倾向报跌倒"的假象（伴随 spec 崩盘证实）；
  其判据依赖轴向信息，轴向一变行为不可控
- **A 在全部条件下 spec ≥ 97.8%，是任意佩戴朝向下唯一可信的版本**
- 真实灵敏度 70~78% vs RF 主判决 96% —— 影子模式的直接依据

## 5. 本轮明确没有动的部分

- cnn_detector.cpp / cnn_detector.h / cnn_weights.h 的板端实现逻辑
- host_replay/ 全部、tools/check_consistency.py、RF 管线（algo/01..05）
- 腕端固件（protocol.h 两端仍逐字节一致）
- 板端归一化换算、窗口/抽取逻辑

## 6. 已验证 / 未验证

**已验证**（本机一键复现，见 §8）：
- check_consistency 22/22 通过（特征序、RF float32 保真、量程标度链等）
- host_replay：Test A 双语言 0 不一致；Test B（本机有 pkl 后首次运行）
  24 真实窗全路径（单位换算→50Hz→抽取）概率偏差 0、跨 0.80 门限翻转 0 个
- Test C 两级判决集成回放通过（含影子模式下的行为）
- v2 训练全流程（smoke + 真数据各一遍）

**未验证**（待实机）：
- 真人佩戴下 CNN p 值的实际分布（影子数据未开始收集）
- RESCUE/VETO 的开启决策（依赖上一条）
- CNN 灵敏度提升空间：正样本仅 370 窗（每 trial 1 正窗 + 1 jitter 副本），
  下轮可增加 jitter 副本数至 3~4 个/受试者试验再对比

## 7. 后续路线（按优先级）

1. 烧录腰端（本版 v0.4，影子模式）→ 正常佩戴测试，串口日志留存
2. 影子数据攒够后统计 2×2 表 → 决定 RESCUE（补漏报）/ VETO（压误报，
   A 的 spec 99.8% 在此方向有潜力）及门限
3. （可选）正样本扩充重训；老年组压测（需确认 pkl 受试者年龄构成）

## 8. 组员复核指引（约 5 分钟）

```bash
python tools/check_consistency.py          # 应 22/22 PASS
python algo/cnn/host_replay/replay.py      # 应 [PASS]，Test B 需本机有 pkl
python algo/cnn/cnn_train.py --smoke       # 应全流程跑通（不落产物）
```

重点复核 `algo/cnn/cnn_train.py` 的 `build_windows()`（锚定切窗）与
`augment_batch()`（旋转/缺失增广）两函数——v2 与 v1 的全部实质差异都在
这两处与划分逻辑。有异议欢迎在分支上改动后开 PR，训练侧脚本与固件
已解耦（归一化口径不变），互不阻塞。

## 9. 环境与数据备忘

- 本机（腰端开发机）已装 TensorFlow 2.21（CPU 版），pkl 位于 algo/data/
  （.gitignore 排除，不入库）；E 盘另存一份原始版 FallAllD.pkl 备查
- cnn_model.h5（v2 旋转版）与训练报告首次入库于 algo/out/，便于复现

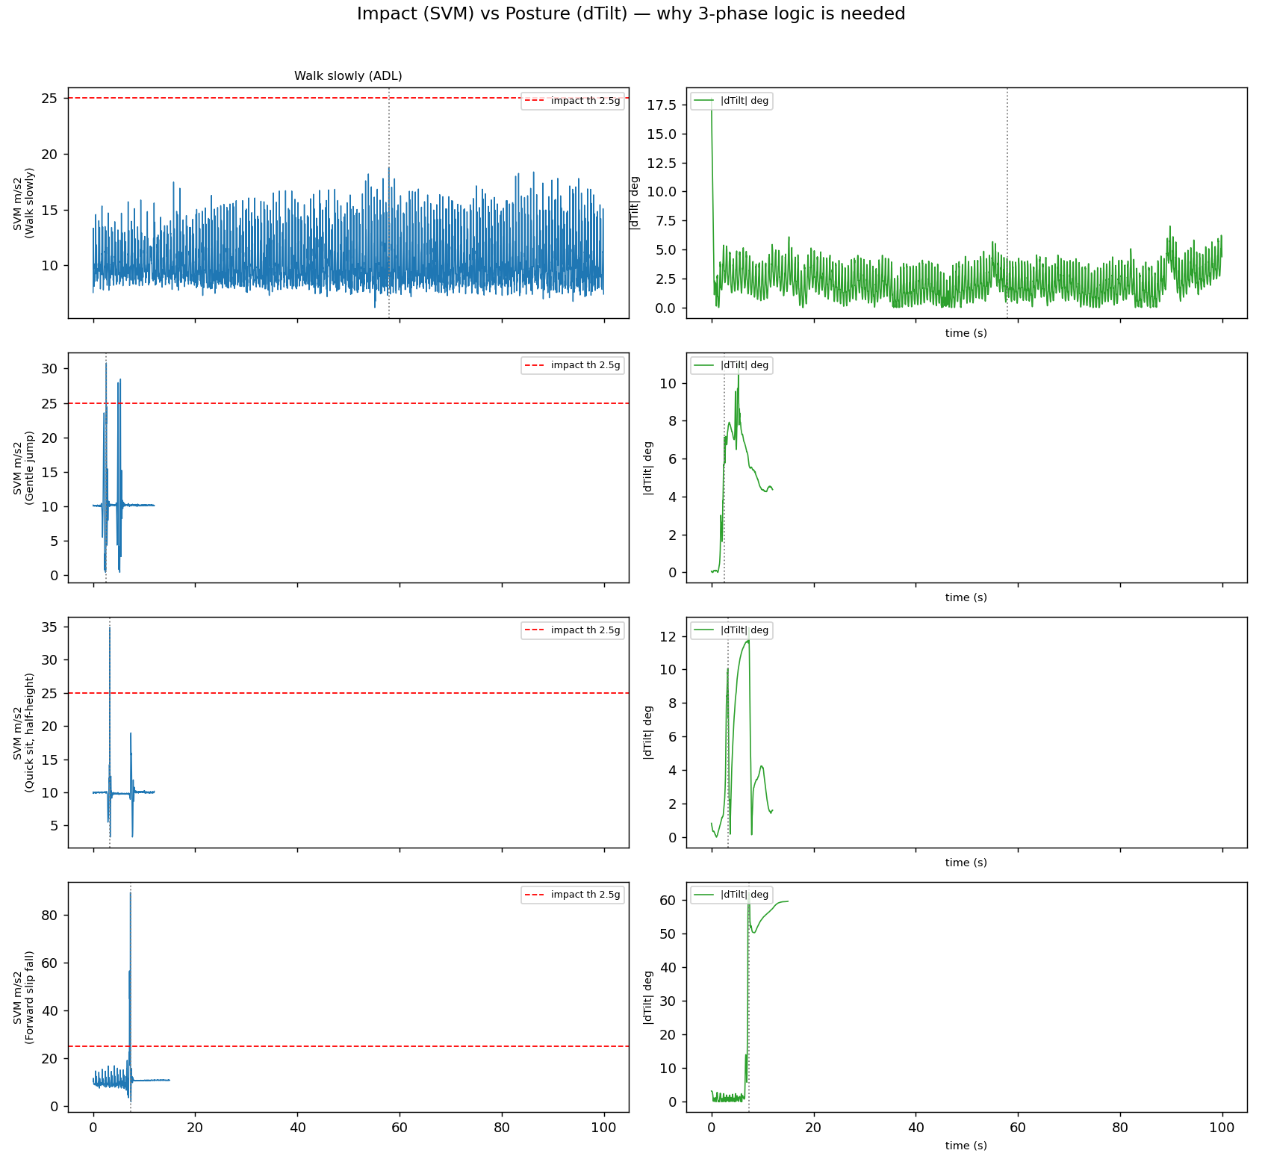
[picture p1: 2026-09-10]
algo/out/explore.png

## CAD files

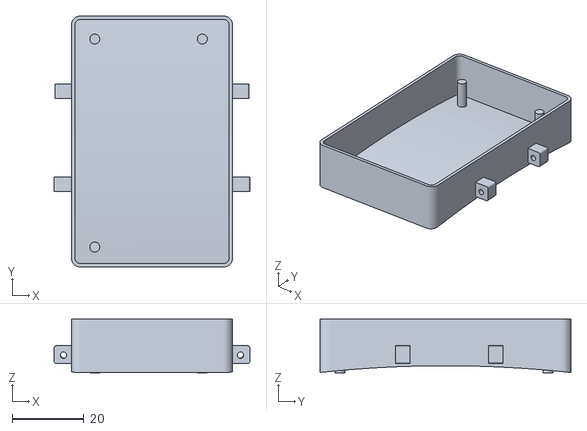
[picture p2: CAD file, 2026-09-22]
hardware/enclosure/腕端最终.stl
54.5 x 70.0 x 15.0

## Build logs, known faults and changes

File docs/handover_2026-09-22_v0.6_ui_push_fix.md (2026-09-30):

# 交接文档 v0.6 —— 产品化 UI + 报警回显 + 步数统计 + 推送加固（2026-09-22）

> 面向：全体组员（v0.6 功能包交接）
> 前置阅读：`handover_2026-09-16_v0.5_on_demand_demo.md`（按需推送/演示脚本，仍然有效）
> 开发分支：`feature/v0.6-ui`（自 `v0.5` tag 起，共 11 个提交）
> 核心原则：**只做旁路改动**——`fall_detector` / `alarm_manager` 状态机 / 采样发送主链路零修改

---

## 1. 本次改动内容（相对 v0.5）

### 1.1 推送文案规范化（腰端 `config.h` 三个宏）

| 项 | 新文案 |
|---|---|
| 消息标题 | `【跌倒报警】请及时关注` |
| 正文 | `【跌倒报警】设备检测到疑似跌倒，7 秒内未按取消键，已确认报警。请尽快联系老人确认状况。` |

只改宏字符串，`net_pusher.cpp` 的拼包逻辑零改动。

### 1.2 报警状态回显：腰→腕 `PKT_ACK`（新通信方向）

协议里预留的 `PKT_ACK`（type=0x03）正式启用，载荷 `AckPayload{alarmState, remainSec}`（2 字节，包大小不变仍 38B）：

- **腰端**（`net_espnow.cpp` 新增 `espnow_send_ack()`）：报警状态变化立即发；取消窗内 2Hz 重发；推送后 1Hz 重发。目标 MAC 取自首个收到的腕端数据包（自动缓存 + add peer，无需配置）。开关 `ENABLE_ALARM_ECHO`（置 0 = 射频行为回到 v0.5）。
- **腕端**（`net_espnow.cpp` 新增接收回调，原本只发不收）：只处理 `PKT_ACK`，只写 4 个 volatile 变量，不碰采样/发送。

### 1.3 腕端 OLED 四级页面（产品化 UI）

优先级从高到低（`ui_oled.cpp`）：

| 页面 | 触发 | 内容 |
|---|---|---|
| 报警弹窗 | alarmState=WAIT | `! FALL DETECTED !` 反色条 + 剩余秒**大字倒计时 7→1** + `WAIST KNOB=CANCEL` |
| 已推送页 | alarmState=SENT | `! FAMILY ALERTED !` + `NOTIFYING VIA WECHAT` |
| 已取消页 | 收到 NORMAL（3 秒） | `CANCELLED` + `FALSE ALARM` |
| 正常页 | 默认 | 运行时长大字 + `STEPS n` + `LINK: OK` |

- **正常页布局开关 `DEBUG_DISPLAY`**（腕端 `config.h`）：0=产品布局（上述）；1=原调试布局（SVM 大字+事件计数）。调试能力保留，一改宏即回。
- 显示滞后 ≤0.5s（OLED 500ms 刷新周期）；推送连 WiFi 期间腕端弹窗可能短暂停在旧状态（信道被占用，推完自动恢复）——均为设计内行为。
- 演示脚本 P17 口径：长按 **1 秒**（`BTN_LONG_PRESS_MS=1000`，中途试过 2s 又按演示需求改回）。

### 1.4 步数统计（腕端纯本地，新模块 `pedometer.h/.cpp`）

- **架构决策：腕端本地算**——本机 50Hz SVM 直接喂入，本地计数、本地 OLED 显示。零通信改动、零协议改动、腰端零依赖。定位：腕端从"只采集转发"升级为"数据本地产出健康指标"。
- 算法（规则法，不训练模型）：动态幅值 `|SVM−9.81|` → EMA 低通（α=0.2）→ 阈值 2.0 m/s² 过阈记候选峰 → 迟滞回差（阈值一半）防抖 → 两峰间隔窗 250~2000ms。
- **两级防误报**：① 阈值挡日常小幅动作；② **连续 4 步确认**——孤立晃动（1~3 峰）不计数，连续走出第 4 步时把前几步一起补记；停走 >2s 重新确认。与报警取消窗同一设计哲学："宁可多一道确认，不做不可靠判定"。
- 存储为 RAM（重启清零）——调试期决策；日后要持久化加 NVS 低频落盘（每小时+每千步）即可，接口已预留 `pedometer_reset()`。
- 调参法（写进 config 注释）：`DEBUG_DISPLAY=1` 走路看 SVM 峰值，阈值 ≈ 峰值动态幅值 × 0.7。**最终调参建议按实际佩戴方式标定**（手持与绑腕数值差异大）。开关 `ENABLE_PEDOMETER`。

### 1.5 WiFi 推送加固（★重要 bug 修复，与时间功能无关）

**修复：推送重试卡死**。原 `connect_wait` 连接超时后不做清理，STA 芯片仍在后台重试连接，15 秒后的下一次 `WiFi.begin()` 被拒（串口铁证：`wifi:sta is connecting, cannot set config`），6 次重试全部假失败。修复：`WiFi.begin` 前先 `WiFi.disconnect()` 清残留 + 超时路径终止后台连接。**此缺陷 v0.2 起就存在，只是"热点先开"的演示流程从未触发过**——任何"第一次连接失败再重试"场景（热点晚开、信号弱）都会踩中，v0.5 同样受影响，属净收益修复。

**新增：失败自动扫描诊断**。推送连接超时后自动全信道扫描 2~4 秒，打印：扫到的 AP 总数、目标热点（信道/信号/加密方式）或"目标不在广播"。本次排查中它一锤定音地区分了"固件问题"与"热点侧问题"（见 §3.1）。

### 1.6 已移除：NTP 时间同步（做过、验证过、主动撤掉）

曾实现"腰端开机一次性 NTP → epoch 经 PKT_ACK 下发 → 腕端走时显示真实时钟"全链路（含失败重试、报警避让），联调中被手机热点问题干扰（见 §3.1），按"推送可靠性优先"原则主动移除。**实现完整封存于 git 历史 `d337728`~`1c87b4f`，恢复直接 cherry-pick**。若日后重启此功能，推荐改用"腰端推送成功时顺手 NTP（复用已建立的 WiFi 连接，零新增射频窗口）+ 时间存 NVS 断电保持"，或腕端低频自连（腕端连 WiFi 期间腰端算法自动回退本地 MPU 判定，安全性已有兜底）。

---

## 2. 烧录与兼容须知

- **v0.6 两端固件必须配套烧录**（协议 `AckPayload` 启用）。混搭不会崩溃（v0.5 腕端会忽略 ACK 包），但弹窗/取消页不出现。
- 版本号：两端 setup 串口打印 `v0.6` 可核对。
- 编译环境不变（Arduino IDE 2.x + ESP32 3.x），无新增库依赖。

## 3. 调试/演示注意事项（实测记录）

### 3.1 手机热点"假死"

现象：热点开关显示"开着"，但 ESP32 扫描全信道找不到它（`diag: TARGET AP NOT in air`），任何设备都连不上；**重启热点立即恢复**。伴随已知问题：安卓"无设备连接自动关热点"（vivo 高发，演示 Checklist 已有预警）。

**演示前固定动作**：① 关闭"无设备连接自动关闭热点"选项；② **上电前重启一次手机热点**（重启即排假死，比"检查开着"可靠）；③ 停留在热点设置页面。

### 3.2 腰端供电与蜂鸣器（待最终确认）

蜂鸣器报警变为"很小的哒哒声"——最大嫌疑是**用 Micro USB（烧录口）长期供电**（5V 且电流弱，蜂鸣器拉电流时电压跌落）。诊断树：换 Type-C/DC ≥6.65V 供电触发报警 → 仍小则蜂鸣器直连 3.3V/5V 测本体 → 本体坏换备件（有第二个）。**演示 Checklist 的"≥6.65V 供电"一条是硬性的。**

### 3.3 lost 计数口径

`lost` 是累计值不回零。WiFi 连接/扫描期间（报警推送、诊断扫描）腕端数据必然断流几十到几百包——属设计内。**看增量不看绝对值**：射频空闲期 lost 增量应为 0。

### 3.4 演示新可展示点

- 报警时腕端 OLED 弹窗+大字倒计时（报警全程腕端有画面）
- 取消后腕端 `CANCELLED` 页
- 正常页 `STEPS`：现场走几步数字跳（连续 4 步起跳，晃一下不涨——可当小互动）

## 4. 已知问题与遗留

| 项 | 状态 | 下一步 |
|---|---|---|
| 蜂鸣器哒哒声 | 疑似供电不足（Micro USB） | 按 §3.2 诊断树确认；演示时用 ≥6.65V |
| 步数灵敏度 | 阈值 2.0（手持标定，近似值） | 按实际佩戴方式依 §1.4 标定法复调 |
| 腰端按钮2（GPIO6） | 预留未实现 | 暂不实现 |
| 时间显示 | 已移除 | 不恢复；恢复路径见 §1.6 |
| 09-14 交接文档遗留 | 已全部完成 | — |

## 5. Git 提交清单与合并（截至本文档提交）

```
b6cc80e feat: 推送文案规范化
b8089ff feat: 报警状态回显(PKT_ACK) + 腕端产品化UI（弹窗/倒计时/取消页，DEBUG_DISPLAY）
d337728 feat: 腕端时钟显示            ┐
82f221f feat: NTP提速+避让            │ 时间功能（已移除，
82b1918 fix:  WiFi重试卡死修复        │ 实现封存于此段历史，
1c87b4f chore: 暂关NTP+推送诊断       │ cherry-pick 可恢复）
435842e diag:  扫描列出全部AP         ┘
8ac5392 revert: 移除NTP时间功能（保留修复与诊断）
6bff15e feat: 腕端步数统计（纯本地）
4f75ac0 fix:  步数防误报（阈值+连续4步确认）
740ef09 fix:  步数阈值回落2.0
```

合并到 main 并打 tag（主开发机执行）：

```bash
git checkout main
git merge feature/v0.6-ui
git tag -a v0.6 -m "v0.6: 产品化UI + 报警回显 + 步数统计 + 推送加固"
git push origin main --tags
git branch -d feature/v0.6-ui
```

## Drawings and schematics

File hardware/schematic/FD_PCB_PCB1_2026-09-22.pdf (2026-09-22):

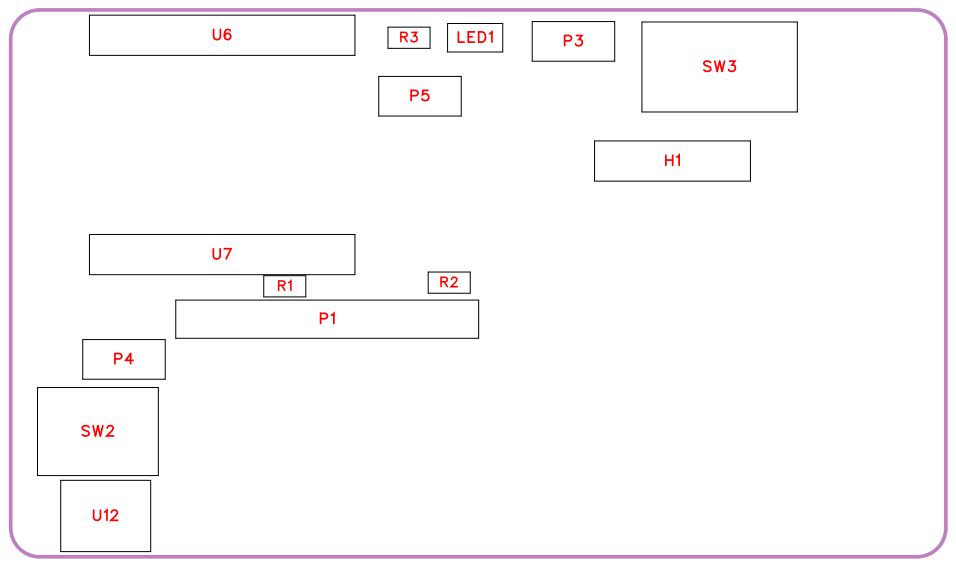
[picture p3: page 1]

No. | Quantity | Comment | Designator | Footprint | Value | Manufacturer Part | Manufacturer | Supplier Part | Supplier
1 | 1 | 2.54-1*4P 母 | H1 | HDR-TH_4P-P2.54-V-F | | 2.54-1*4P 母 | BOOMELE( ) 博穆精密 | C2718488 | LCSC
2 | 1 | 150060YS75 000 | LED1 | LED0603-R-RD_YELLO W | | 150060YS75 000 | | C990001228 6 | LCSC
3 | 1 | 2.54-1*8P 母 环保 | P1 | HDR-TH_8P-P2.54-V-F | | 2.54-1*8P 母 环保 | BOOMELE( ) 博穆精密 | C27438 | LCSC
4 | 1 | J7 BTN外接 | P3 | HDR-TH_2P-P2.54-V-F | | J7 BTN外接 | BOOMELE( 博穆精密 ) | C49661 | LCSC
5 | 1 | J8 开关旁路 | P4 | HDR-TH_2P-P2.54-V-F | | J8 开关旁路 | BOOMELE( 博穆精密 ) | C49661 | LCSC
6 | 1 | J10 BAT引线 | P5 | HDR-TH_2P-P2.54-V-F | | J10 BAT引线 | BOOMELE( 博穆精密 ) | C49661 | LCSC
7 | 2 | 4.7k | R1,R2 | R0603 | 4.7k | 0603WAF47 01T5E | UNI-ROYAL( ) 厚声 | C23162 | LCSC
8 | 1 | 1k | R3 | R0603 | 1k | RC0603FR-0 71KL | YAGEO(国巨 ) | C22548 | LCSC
9 | 1 | MSK-12C02-1_5Hgge12 | SW2 | SW-TH_MSK 12C02 | | SW2 滑动 | | C990001830 5 | LCSC
10 | 1 | SW1 | SW3 | KEY-SMD_4 P-L6.0-W6.0-P4.50-LS8.6 _H8.5 | | SW1 轻触 | Megastar( 兆 星 ) | C7470159 | LCSC
11 | 1 | J1 XIAO 座 A | U6 | HDR-TH_7P-P2.54-V-M-1 | | J1 XIAO 座 A | | C990003449 7 | LCSC
12 | 1 | J2 XIAO B 座 | U7 | HDR-TH_7P-P2.54-V-M-1 | | J2 XIAO B 座 | | C990003449 7 | LCSC
13 | 1 | J9 电池座 | U12 | CONN-TH_2 P-P2.00_BO SSIE_BX-PH 2.0-2PZZ | | J9 电池座 | | C990009516 2 | LCSC

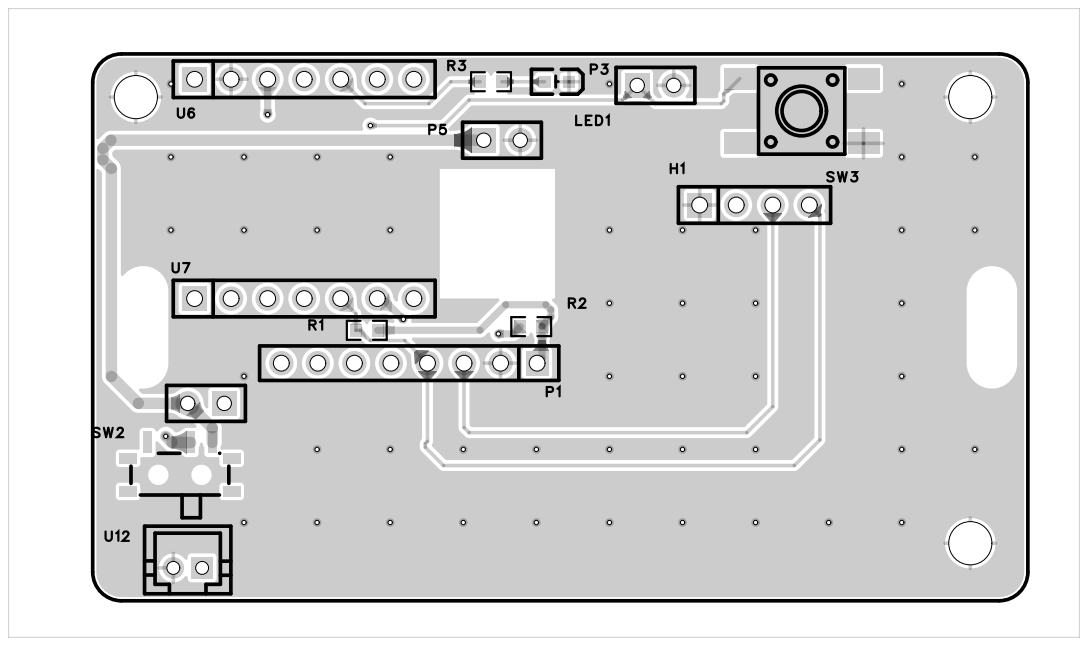
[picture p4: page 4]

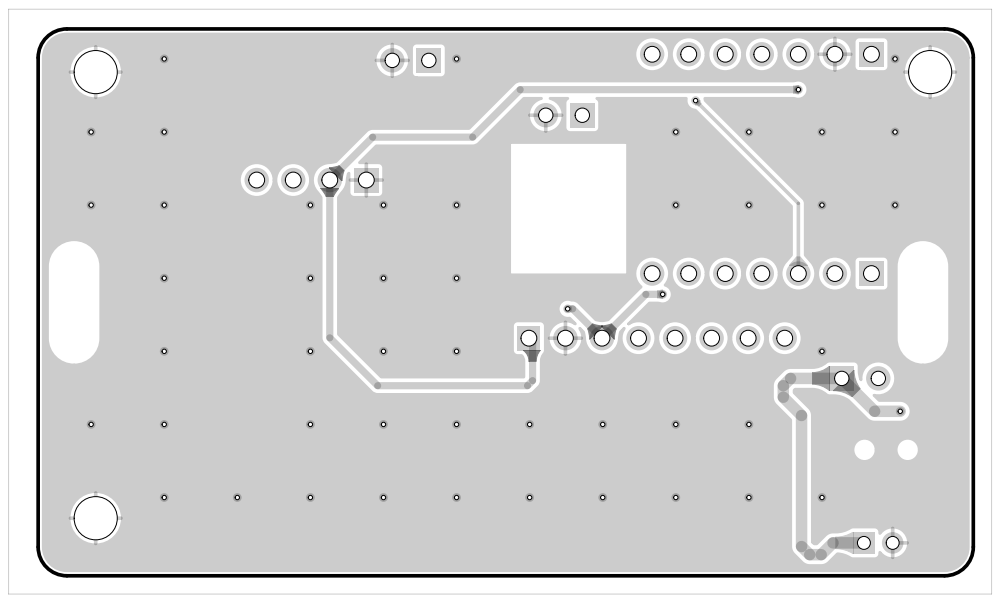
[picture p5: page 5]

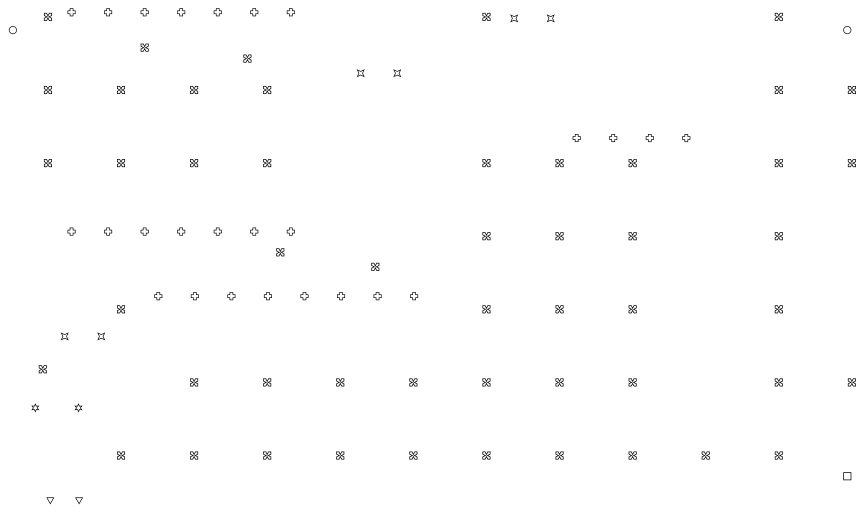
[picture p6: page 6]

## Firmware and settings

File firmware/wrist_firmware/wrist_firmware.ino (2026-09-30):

// ============================================================
//  腕端固件入口 — XIAO ESP32S3
//  智能跌倒检测报警器 · 清华第29届硬件设计大赛
//  职责：采集姿态 → OLED 显示 → ESP-NOW 发送 → 腰端
//
//  任务一览（FreeRTOS，全部跑在 core1，WiFi 协议栈在 core0）：
//    task_sensor   50Hz  高   读 MPU → 写共享数据 g_sensor_data（含步数统计）
//    task_tx       50Hz  高   读共享数据 → ESP-NOW 发送
//    task_button   20Hz  中   按钮扫描（去抖+短/长按）
//    task_led      20Hz  低   状态 LED 步进闪烁
//    task_display   2Hz  低   OLED 刷新
//
//  跌倒判定不在腕端：ENABLE_FALL_DETECT=0 时长按按钮发"模拟跌倒"
//  命令给腰端，触发完整报警链路（主动呼救 / 联调模拟共用）
// ============================================================
#include "config.h"
#include "logger.h"
#include "protocol.h"
#include "sensor_manager.h"
#include "ui_oled.h"
#include "ui_button.h"
#include "hw_led.h"
#include "pedometer.h"
#include "net_espnow.h"
#include <Wire.h>
#include <freertos/FreeRTOS.h>
#include <freertos/task.h>

// ================= 运行状态（display/日志共用） =================
static volatile uint32_t g_evt_cnt   = 0;   // 按钮事件累计
static volatile uint32_t g_sim_until = 0;   // 模拟跌倒提示截止时刻（OLED 显示用）

// ================= 任务实现 =================

// 传感器采样：严格 50Hz（vTaskDelayUntil 保证周期稳定，不累积误差）
static void task_sensor(void* pv) {
    TickType_t last = xTaskGetTickCount();
    const TickType_t period = pdMS_TO_TICKS(1000 / SAMPLE_HZ);
    for (;;) {
        vTaskDelayUntil(&last, period);
        bool ok = sensor_manager_read();
        led_report_mpu(ok);              // LED 快闪 = MPU 离线
#if ENABLE_PEDOMETER
        // 步数统计：读成功后取共享快照喂入（锁内纯计算，耗时纳秒级）
        if (ok && xSemaphoreTake(g_sensor_mutex, pdMS_TO_TICKS(10))) {
            pedometer_feed(g_sensor_data.svm);
            xSemaphoreGive(g_sensor_mutex);
        }
#endif
        if (!ok) {
            // MPU 离线（read 内部已重试），降频打印避免刷屏
            static uint32_t lastErr = 0;
            if (millis() - lastErr > 1000) {
                LOG_E("SENS", "MPU offline, retrying...");
                lastErr = millis();
            }
        }
    }
}

// 无线发送：复制一份共享数据快照再打包（持锁时间最短化）
static void task_tx(void* pv) {
    TickType_t last = xTaskGetTickCount();
    const TickType_t period = pdMS_TO_TICKS(1000 / SAMPLE_HZ);
    for (;;) {
        vTaskDelayUntil(&last, period);
        SensorData snap;
        if (xSemaphoreTake(g_sensor_mutex, pdMS_TO_TICKS(10))) {
            snap = g_sensor_data;
            xSemaphoreGive(g_sensor_mutex);
        } else {
            continue;   // 偶发拿不到锁：跳过本帧，不阻塞任务
        }
        espnow_send_data(snap);
        led_report_tx(g_espnow_last_ok);   // LED 慢闪 = 连续发送失败（链路故障）
    }
}

// 状态 LED：50ms 步进闪烁状态机（闪烁含义见 hw_led.h）
static void task_led(void* pv) {
    for (;;) {
        vTaskDelay(pdMS_TO_TICKS(50));
        led_tick();
    }
}

// 按钮扫描：短按=交互（翻页 TODO），长按=主动呼救（联调时兼作模拟跌倒）
static void task_button(void* pv) {
    for (;;) {
        vTaskDelay(pdMS_TO_TICKS(BUTTON_POLL_MS));
        ButtonEvent e = button_poll();
        if (e == BTN_NONE) continue;

        g_evt_cnt++;
        if (e == BTN_SHORT) {
            LOG_I("BTN", "short press (evt=%lu)", (unsigned long)g_evt_cnt);
            // TODO(交互)：OLED 多页显示时在此切换页面
        } else {  // BTN_LONG
            LOG_I("BTN", "long press -> SIM FALL");
#if ENABLE_FALL_DETECT
            // 算法启用后，模拟功能关闭（避免干扰真实判定）
            LOG_I("BTN", "fall detect enabled, sim ignored");
#else
            espnow_send_cmd(CMD_SIM_FALL);
            g_sim_until = millis() + 3000;   // OLED 提示 3 秒
#endif
        }
    }
}

// OLED 刷新：组装 UiInfo → 刷新（慢速低优先级，绝不干扰采样）
static void task_display(void* pv) {
    for (;;) {
        vTaskDelay(pdMS_TO_TICKS(DISPLAY_PERIOD_MS));

        UiInfo info = {};
        // —— 腰端报警状态（v0.6 PKT_ACK 回显；4s 无新包则老化回正常，防误锁弹窗）——
        uint8_t st = g_alarm_state;
        if (st != ACK_ALARM_NORMAL && millis() - g_alarm_rx_ms > 4000) {
            st = ACK_ALARM_NORMAL;
        }
        info.alarmState = st;
        info.remainSec  = g_alarm_remain;
        info.cancelled  = (millis() < g_cancel_until_ms);
        info.simActive  = (millis() < g_sim_until);
        if (xSemaphoreTake(g_sensor_mutex, pdMS_TO_TICKS(10))) {
            info.svm = g_sensor_data.svm;
            xSemaphoreGive(g_sensor_mutex);
        }
        info.uptime = millis() / 1000;
        info.evtCnt = g_evt_cnt;
        info.linkOk = g_espnow_last_ok;
        info.steps  = pedometer_get_steps();   // 今日步数（本地计数）
        oled_update(info);
    }
}

// ================= 入口 =================
void setup() {
    Serial.begin(SERIAL_BAUD);
    delay(200);
    LOG_I("SYS", "=== wrist firmware v0.6 (alarm echo + product UI) ===");

    // I2C 总线先行（OLED 与 MPU 共用）
    Wire.begin(PIN_I2C_SDA, PIN_I2C_SCL);
    // 保持默认 100kHz：补焊总线信号质量有限，400kHz 实测不稳（MPU 离线）
    // 50Hz 采样每帧约 14 字节，100kHz 下仅占 1.3ms，带宽余量充足

    // —— 各模块初始化：失败不阻塞（对应开关关掉/硬件后补，其余照常跑）——
#if ENABLE_MPU6050
    LOG_I("SYS", "MPU init ... %s", sensor_manager_init() ? "ok" : "FAIL(0x68 not found)");
#else
    sensor_manager_init();   // 仅创建互斥锁，填充模拟数据
    LOG_I("SYS", "MPU disabled, mock data mode");
#endif

#if ENABLE_OLED
    LOG_I("SYS", "OLED init ... %s", oled_init() ? "ok" : "FAIL(0x3C not found)");
    oled_show_boot();
#else
    LOG_I("SYS", "OLED disabled");
#endif

#if ENABLE_BUTTON
    button_init();
    LOG_I("SYS", "button init ok (GPIO%d)", PIN_BTN_1);
#endif

#if ENABLE_LED
    led_init();
    LOG_I("SYS", "led init ok (GPIO%d)", PIN_LED);
#endif

#if ENABLE_ESPNOW
    espnow_init();
#else
    LOG_I("SYS", "ESP-NOW disabled");
#endif

    // —— 创建任务（core1；栈大小按 printf 浮点需求留足）——
    xTaskCreatePinnedToCore(task_sensor,  "sensor",  4096, nullptr, 3, nullptr, 1);
    xTaskCreatePinnedToCore(task_tx,      "tx",      4096, nullptr, 3, nullptr, 1);
#if ENABLE_BUTTON
    xTaskCreatePinnedToCore(task_button, "button", 2048, nullptr, 2, nullptr, 1);
#endif
#if ENABLE_LED
    xTaskCreatePinnedToCore(task_led,    "led",    2048, nullptr, 1, nullptr, 1);
#endif
#if ENABLE_OLED
    xTaskCreatePinnedToCore(task_display, "display", 4096, nullptr, 1, nullptr, 1);
#endif

    LOG_I("SYS", "all tasks started");
}

// 全部工作在 FreeRTOS 任务中，loop 空转（永久让出）
void loop() {
    vTaskDelay(portMAX_DELAY);
}

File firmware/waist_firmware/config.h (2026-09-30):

#pragma once
// ============================================================
//  腰端全局配置 — ESP32-S3 大板（ESP32-S3-WROOM-1-N16R8 课程板）
//  所有引脚、参数、功能开关集中于此，改一处全局生效
//  分段调试原则：哪个模块没接好/没到货，把对应 ENABLE 置 0 即可
// ============================================================

// ================= 硬件引脚（大板排针 H4） =================
#define PIN_I2C_SDA         8       // 腰端 MPU6500，排针 H4 第12脚，开漏需上拉
#define PIN_I2C_SCL         9       // 排针 H4 第15脚
#define PIN_BUZZER          4       // 有源蜂鸣器模块（板载 S8050 驱动，高电平响），H4 第4脚
                                    // 接线：VCC→5V，GND→GND，I/O→本脚；2026-09-10 采购
#define PIN_BTN_CANCEL      5       // 取消报警按钮，H4 第5脚，另一端接 GND

// ================= 大板注意事项（烧录/供电） =================
// 烧录口：Micro USB（CH340 串口），不是 Type-C
// 供电：Type-C/DC5521，输入必须 ≥6.65V，5V 充电宝直连 Type-C 无法启动
// 烧录选项：板选 ESP32S3 Dev Module，USB CDC in Boot = Disable

// ================= 设备 I2C 地址 =================
#define ADDR_MPU6050        0x68    // 腰端 MPU（实测为 MPU6500，寄存器与 MPU6050 兼容）

// ================= ESP-NOW 通信 =================
// ★常连模式(PUSH_ALWAYS_ON=1)约束：必须与热点信道一致（单射频只有一个信道）！
//   上次实测 vivo 热点在 ch6。串口看 "WiFi connected ... ch=X"，
//   若 X != 本值会有 [PUSH] !! 告警 —— 按实际信道改这里和腕端 config.h
#define ESPNOW_CHANNEL      6       // 与腕端一致（有效范围 1~13）
// 腕端 MAC：当前不做过滤（按包内 devId 过滤），联调稳定后可改单播

// ================= 报警参数（有源蜂鸣器：固定音调，节奏由通断时序控制） =================
// 两段式报警音：取消窗内急促短哔（提醒本人取消），推送后转长鸣（吸引周围人）
#define ALARM_CANCEL_WINDOW_MS   7000    // 触发报警后的取消窗口（毫秒）。
                                         // 2026-09-14: 10s→7s，演示节奏更快；
                                         // 量产定位建议 ≥8s（给老人留反应时间），下限 6s
#define ALARM_BEEP_ON_MS         300     // 阶段1（取消窗内）哔声时长
#define ALARM_BEEP_PERIOD_MS     500     // 阶段1 哔声周期（300 响 + 200 停）
#define ALARM_BEEP_ON_MS_LATE    800     // 阶段2（已推送）哔声时长
#define ALARM_BEEP_PERIOD_MS_LATE 1000   // 阶段2 哔声周期（800 响 + 200 停）

// ================= 采样与任务参数 =================
#define SAMPLE_HZ           50      // 本地 MPU 采样率
#define BUTTON_POLL_MS      50      // 按钮扫描周期
#define ALARM_TICK_MS       100     // 报警状态机步进周期
#define STAT_PERIOD_MS      10000   // 链路统计打印周期：联调阶段可改 1000 看实时丢包，
                                    // 平时 10 秒一条即可；想完全关闭把 LOG_LEVEL 改 2

// ================= 分级调试开关 =================
#define LOG_LEVEL           3       // 0=关 1=错误 2=信息 3=调试

#define ENABLE_MPU6050      1       // 0 = 不读本地 MPU（只收腕端数据调试链路）
#define ENABLE_ESPNOW       1       // 0 = 不初始化无线（单板调试蜂鸣器/按钮）
#define ENABLE_BUZZER       1       // 0 = 不响（调试时防止吵）；有源模块已接线后置 1
#define ENABLE_BUTTON       1       // 0 = 不扫描按钮

#define ENABLE_FALL_DETECT  1       // ★跌倒判定算法（已实现：三阶段触发+小随机森林）
                                    // 0 = 未启用，仅腕端"长按模拟跌倒"可触发报警（联调用）
                                    // 1 = 启用板上算法（上板验证通过后打开）
// ---- 算法参数（由 algo/04_threshold.py 在训练集上标定，改动需重评）----
#define FD_TRIGGER_SVM      30.0f   // 冲击触发阈值 m/s²（≈3.1g）
#define FD_TRIGGER_GYR      200.0f  // 角速度触发阈值 °/s（与 SVM 满足其一即触发）
#define FD_RF_THRESHOLD     0.40f   // 随机森林判决门限：灵敏96% 特异98.4% 老年FP4.6%
                                    // （调低更灵敏误报升；自采数据验证后可微调）
#define FD_BASELINE_MS      5000    // 开机站姿基线采集时长（期间不判定，需保持站立）
#define FD_COLLECT_MS       3500    // 触发后确认窗采集时长（峰值+3s 确认窗）

// ---- 腕端融合 v1：否决票（自采数据验证标定后再启用）----
// 逻辑：腕端链路健康 && 腰端强冲击 && 腕端几乎没动 -> 判为"装置被磕碰"否决报警。
// 三个阈值均为工程初值，待自采数据回放标定（wrist 数据无论开关都记录在串口）
#define ENABLE_WRIST_FUSION      0       // 1=启用腕端否决票（腕端需开机且链路正常）
#define FUSION_MIN_COVERAGE      0.6f    // 腕端冲击窗数据覆盖率下限（低于=数据不可信，不否决）
#define FUSION_VETO_WAIST_STRONG 30.0f   // 腰端冲击峰值下限 m/s²（约3g）
#define FUSION_VETO_WRIST_QUIET  12.0f   // 腕端峰值上限 m/s²（约1.2g，静止水平）
#define WRIST_FRESH_MS           200     // 腕端数据新鲜度判据（remoteAge 小于此=有效样本）

// ---- CNN 二级仲裁（第二级判决，实现见 cnn_detector.cpp / cnn_weights.h）----
// 架构：随机森林仍是主判决（三阶段触发 -> 特征 -> RF）。
//       CNN 只在"腰端已触发冲击 + 判定时腕端链路在线"时补跑一次推理
//       （每次事件最多 1 次），不参与常态判决，CPU 开销可忽略。
//       腕端不在线 / 仲裁窗覆盖率不足 -> 直接不跑，行为完全回退到纯 RF。
// 训练/导出链路：algo/cnn/cnn_train.py -> firmware/waist_firmware/cnn_weights.h
#define ENABLE_CNN_ARBITER  1       // 1=启用 CNN 二级仲裁（0=纯 RF，与 v2 行为一致）
#define CNN_ROLE_RESCUE     0       // 1=允许 CNN 补判 RF 漏掉的跌倒（补漏报）
                                    //   ★ 2026-09-11 影子模式：当前 CNN 尚未经过
                                    //   按人划分的真实评估，不允许它改变判决结果。
                                    //   影子期只看日志（decision 后的 "cnn p=..." 行），
                                    //   攒够"RF 对/错 × CNN 高/低"对照数据后再开
#define CNN_ROLE_VETO       0       // 1=允许 CNN 否决 RF 的"跌倒"判决（压误报）
                                    //   ★ 会压低灵敏度，须用自采数据标定后再开
#define CNN_FALL_THRESHOLD  0.80f   // CNN 判"跌倒"门限（＝训练侧部署门限）
#define CNN_CALM_THRESHOLD  0.20f   // CNN 判"明确非跌倒"门限（仅否决票用）
#define CNN_MIN_COVERAGE    0.6f    // 仲裁窗腕端覆盖率下限（同 FUSION_MIN_COVERAGE 口径）

#define ENABLE_WIFI_PUSH    1       // 微信推送（已实现：队列+独立任务+WxPusher HTTPS）
                                    // 需要 secrets.h（复制 secrets.h.example 填真实值）
                                    // ★ 该文件不入库；缺失时 net_pusher 自动降级为
                                    //   占位实现并给编译告警，不会让工程编译不过
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

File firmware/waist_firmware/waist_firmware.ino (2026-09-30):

// ============================================================
//  腰端固件入口 — ESP32-S3 大板（主控）
//  智能跌倒检测报警器 · 清华第29届硬件设计大赛
//  职责：本地采集 + 接收腕端数据 + 融合判断（算法组）+ 报警 + 推送
//
//  任务一览（FreeRTOS，全部跑在 core1，WiFi 协议栈在 core0）：
//    task_sensor  50Hz  高   读本地 MPU → g_local_data
//    task_detect  50Hz  高   组装两端数据 → fall_detector（算法组）
//    task_button  20Hz  中   取消按钮扫描（去抖）
//    task_alarm   10Hz  高   报警状态机（哔哔节拍 + 推送窗口）
//    task_alarm_echo 5Hz 低  报警状态回显发送（独立任务，避免射频操作拖住蜂鸣节拍）
//    task_stat     1Hz  低   链路统计打印（收包/丢包）
//
//  烧录（重要）：
//    板选 ESP32S3 Dev Module，USB CDC in Boot = Disable
//    烧录口 = Micro USB（CH340 串口）；供电 Type-C/DC5521 需 ≥6.65V
// ============================================================
#include "config.h"
#include "logger.h"
#include "protocol.h"
#include "sensor_manager.h"
#include "hw_buzzer.h"
#include "hw_button.h"
#include "fall_detector.h"
#include "alarm_manager.h"
#include "net_espnow.h"
#include "net_pusher.h"
#include <Wire.h>
#include <freertos/FreeRTOS.h>
#include <freertos/task.h>

// ================= 任务实现 =================

// 本地传感器采样：严格 50Hz
static void task_sensor(void* pv) {
    TickType_t last = xTaskGetTickCount();
    const TickType_t period = pdMS_TO_TICKS(1000 / SAMPLE_HZ);
    for (;;) {
        vTaskDelayUntil(&last, period);
        if (!sensor_manager_read()) {
            static uint32_t lastErr = 0;
            if (millis() - lastErr > 1000) {
                LOG_E("SENS", "local MPU offline, retrying...");
                lastErr = millis();
            }
        }
    }
}

// 检测任务：取两端快照 → 算法判定 → 触发报警
static void task_detect(void* pv) {
    TickType_t last = xTaskGetTickCount();
    const TickType_t period = pdMS_TO_TICKS(1000 / SAMPLE_HZ);
    for (;;) {
        vTaskDelayUntil(&last, period);
#if ENABLE_FALL_DETECT
        FallInput in = {};
        if (xSemaphoreTake(g_sensor_mutex, pdMS_TO_TICKS(10))) {
            in.local  = g_local_data;
            in.remote = g_remote_data;
            xSemaphoreGive(g_sensor_mutex);
        }
        in.hasRemote = sensor_manager_has_remote(&in.remoteAgeMs);

        if (fall_detector_update(in) == FALL_CONFIRMED) {
            alarm_trigger("algo");
        }
#else
        // 算法未启用：本任务空转（链路由腕端 SIM_FALL 命令触发）
#endif
    }
}

// 取消按钮：按下即取消报警（含已推送状态）
static void task_button(void* pv) {
    for (;;) {
        vTaskDelay(pdMS_TO_TICKS(BUTTON_POLL_MS));
        if (button_poll() == CBTN_PRESSED) {
            LOG_I("BTN", "cancel pressed");
            alarm_cancel();
        }
    }
}

// 报警状态机步进：哔哔节拍 + 取消窗口超时推送
// ★此任务必须纯净：只调 alarm_tick()，绝不碰射频/WiFi API——
//   v0.6 曾把回显发送放在这里，推送连 WiFi 期间 esp_now_send 被射频驱动
//   拖住，导致 alarm_tick 停跑、蜂鸣器响 7 秒后停（已修复，见 task_alarm_echo）
static void task_alarm(void* pv) {
    for (;;) {
        vTaskDelay(pdMS_TO_TICKS(ALARM_TICK_MS));
        alarm_tick();
    }
}

#if ENABLE_ALARM_ECHO
// 报警状态回显发送：独立低优先级任务（宁可它被拖住，不拖蜂鸣节拍）
// 发送时机：状态变化立即发；取消窗内 2Hz 重发（此阶段无 WiFi 活动，安全）。
// ★ST_SENT 期间不重发：推送正在连 WiFi，发包与射频驱动并发会阻塞调用者
//   （腕端若错过 SENT 那一包，4s 后自动老化回正常页，属可接受的降级）
static void task_alarm_echo(void* pv) {
    static AlarmState s_last = ST_NORMAL;
    static uint32_t   s_last_ms = 0;
    for (;;) {
        vTaskDelay(pdMS_TO_TICKS(200));
        AlarmState st  = alarm_state();
        uint32_t   now = millis();
        bool send = (st != s_last)
                 || (st == ST_WAIT_CANCEL && now - s_last_ms >= 500);
        if (send) {
            uint8_t remain = 0;
            if (st == ST_WAIT_CANCEL) {
                uint32_t leftMs = ALARM_CANCEL_WINDOW_MS - alarm_elapsed_ms();
                remain = (uint8_t)((leftMs + 999) / 1000);   // 向上取整（OLED 大字显示）
            }
            espnow_send_ack((uint8_t)st, remain);
            s_last_ms = now;
        }
        s_last = st;
    }
}
#endif

// 链路统计：1Hz 打印收包/丢包（LOG_LEVEL>=3 时输出）
static void task_stat(void* pv) {
    for (;;) {
        vTaskDelay(pdMS_TO_TICKS(STAT_PERIOD_MS));
        uint32_t rx = 0, lost = 0, age = 0;
        espnow_get_stats(&rx, &lost, &age);
        LOG_D("STAT", "rx=%lu lost=%lu lastAge=%lums state=%d",
              (unsigned long)rx, (unsigned long)lost, (unsigned long)age, alarm_state());
    }
}

// ================= 入口 =================
void setup() {
    Serial.begin(SERIAL_BAUD);
    delay(200);
    LOG_I("SYS", "=== waist firmware v0.6 (alarm echo moved to own task) ===");

    // I2C：大板 GPIO8/9（默认 100kHz，稳定性优先）
    Wire.begin(PIN_I2C_SDA, PIN_I2C_SCL);

    // —— 各模块初始化：失败不阻塞，分级开关见 config.h ——
    alarm_init();   // 蜂鸣器静音初始化（确保上电不响）

#if ENABLE_MPU6050
    LOG_I("SYS", "local MPU init ... %s", sensor_manager_init() ? "ok" : "FAIL(0x68 not found)");
#else
    sensor_manager_init();   // 仅创建互斥锁
    LOG_I("SYS", "local MPU disabled (rx-only mode)");
#endif

#if ENABLE_BUTTON
    button_init();
    LOG_I("SYS", "cancel button init ok (GPIO%d)", PIN_BTN_CANCEL);
#endif

#if ENABLE_ESPNOW
    espnow_init();
#else
    LOG_I("SYS", "ESP-NOW disabled");
#endif

#if ENABLE_WIFI_PUSH
    pusher_init();   // 推送队列 + 最低优先级推送任务
    LOG_I("SYS", "wifi push enabled");
#endif

    // —— 创建任务（core1）——
    xTaskCreatePinnedToCore(task_sensor, "sensor", 4096, nullptr, 3, nullptr, 1);
    xTaskCreatePinnedToCore(task_detect, "detect", 4096, nullptr, 3, nullptr, 1);
#if ENABLE_BUTTON
    xTaskCreatePinnedToCore(task_button, "button", 2048, nullptr, 2, nullptr, 1);
#endif
    xTaskCreatePinnedToCore(task_alarm,  "alarm",  2048, nullptr, 3, nullptr, 1);
    xTaskCreatePinnedToCore(task_stat,   "stat",   2048, nullptr, 1, nullptr, 1);
#if ENABLE_ALARM_ECHO
    xTaskCreatePinnedToCore(task_alarm_echo, "alarm_echo", 3072, nullptr, 1, nullptr, 1);
#endif

    LOG_I("SYS", "all tasks started");
}

// 全部工作在 FreeRTOS 任务中，loop 空转
void loop() {
    vTaskDelay(portMAX_DELAY);
}

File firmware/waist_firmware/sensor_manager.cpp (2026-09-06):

// ============================================================
//  传感器管理（腰端）实现 — 裸寄存器驱动
//  与腕端 sensor_manager.cpp 同款驱动（实测模块可能是 MPU6500，
//  WHO_AM_I=0x70，寄存器与 MPU6050 兼容），另含远端数据存储
//  踩坑记录见 docs/notes/mpu6500_driver_note.md
// ============================================================
#include "sensor_manager.h"
#include "logger.h"
#include "config.h"
#include <math.h>
#include <Wire.h>

// ---- MPU 寄存器地址（6050/6500 兼容） ----
#define REG_SMPLRT_DIV   0x19  // 采样率分频
#define REG_CONFIG       0x1A  // DLPF 数字低通滤波
#define REG_GYRO_CFG     0x1B  // 陀螺仪量程
#define REG_ACCEL_CFG    0x1C  // 加速度计量程
#define REG_DATA         0x3B  // 数据区起始（14 字节）
#define REG_PWR_MGMT_1   0x6B  // 电源管理
#define REG_WHO_AM_I     0x75  // 芯片 ID

// ---- 量程换算系数（±8g / ±500 deg/s） ----
static const float ACCEL_LSB = (8.0f * 9.80665f) / 32768.0f;  // m/s²/LSB
static const float GYRO_LSB  = 500.0f / 32768.0f;             // deg/s/LSB

// ---- 全局共享数据（local=腰端 MPU，remote=腕端无线数据） ----
SensorData        g_local_data  = {};
SensorData        g_remote_data = {};
SemaphoreHandle_t g_sensor_mutex = nullptr;

// ---- 远端数据时效（供 FallInput.remoteAgeMs） ----
static volatile uint32_t s_remote_last_ms = 0;
static volatile bool     s_has_remote     = false;

static bool s_mpu_ok = false;

// ---- 基础寄存器访问 ----
static void mpu_write(uint8_t reg, uint8_t val) {
    Wire.beginTransmission(ADDR_MPU6050);
    Wire.write(reg);
    Wire.write(val);
    Wire.endTransmission();
}

static uint8_t mpu_read(uint8_t reg) {
    Wire.beginTransmission(ADDR_MPU6050);
    Wire.write(reg);
    Wire.endTransmission(false);              // repeated start
    Wire.requestFrom(ADDR_MPU6050, 1);
    return Wire.available() ? Wire.read() : 0xFF;
}

bool sensor_manager_init(void) {
    if (g_sensor_mutex == nullptr) {
        g_sensor_mutex = xSemaphoreCreateMutex();
    }

#if ENABLE_MPU6050
    uint8_t id = mpu_read(REG_WHO_AM_I);
    if (id == 0x00 || id == 0xFF) {
        LOG_E("SENS", "MPU not responding (id=0x%02X)", id);
        return false;
    }
    LOG_I("SENS", "MPU chip ID=0x%02X (%s)", id,
          id == 0x68 ? "MPU6050" :
          id == 0x70 ? "MPU6500" :
          id == 0x71 ? "MPU6515" : "compatible chip");

    mpu_write(REG_PWR_MGMT_1, 0x01);   // 唤醒，时钟=陀螺 PLL
    mpu_write(REG_SMPLRT_DIV, 0x04);   // 内部采样 200Hz
    mpu_write(REG_CONFIG, 0x04);       // DLPF≈20Hz
    mpu_write(REG_ACCEL_CFG, 0x10);    // ±8g
    mpu_write(REG_GYRO_CFG, 0x08);     // ±500 deg/s
    delay(10);
    return true;
#else
    return true;
#endif
}

bool sensor_manager_read(void) {
#if ENABLE_MPU6050
    if (!s_mpu_ok) {
        s_mpu_ok = sensor_manager_init();
        if (!s_mpu_ok) return false;
    }

    Wire.beginTransmission(ADDR_MPU6050);
    Wire.write(REG_DATA);
    if (Wire.endTransmission(false) != 0) {
        s_mpu_ok = false;
        return false;
    }
    uint8_t buf[14];
    if (Wire.requestFrom(ADDR_MPU6050, 14) != 14) {
        s_mpu_ok = false;
        return false;
    }
    for (int i = 0; i < 14; i++) buf[i] = Wire.read();
    // buf[6..7] 是温度，暂不使用

    SensorData d;
    d.ax = (int16_t)((buf[0] << 8) | buf[1])   * ACCEL_LSB;
    d.ay = (int16_t)((buf[2] << 8) | buf[3])   * ACCEL_LSB;
    d.az = (int16_t)((buf[4] << 8) | buf[5])   * ACCEL_LSB;
    d.gx = (int16_t)((buf[8] << 8) | buf[9])   * GYRO_LSB;
    d.gy = (int16_t)((buf[10] << 8) | buf[11]) * GYRO_LSB;
    d.gz = (int16_t)((buf[12] << 8) | buf[13]) * GYRO_LSB;
    d.svm = sqrtf(d.ax * d.ax + d.ay * d.ay + d.az * d.az);
    d.ts  = millis();

    if (xSemaphoreTake(g_sensor_mutex, pdMS_TO_TICKS(10))) {
        g_local_data = d;
        xSemaphoreGive(g_sensor_mutex);
        return true;
    }
    return false;
#else
    return true;   // 本地 MPU 关闭：检测自动降级为纯远端模式
#endif
}

void sensor_manager_set_remote(const SensorData& d) {
    if (xSemaphoreTake(g_sensor_mutex, 0)) {   // 不等待：回调上下文禁止阻塞
        g_remote_data = d;
        xSemaphoreGive(g_sensor_mutex);
        s_remote_last_ms = millis();
        s_has_remote = true;
    }
    // 拿不到锁则丢弃本包：50Hz 流，丢一帧无碍
}

bool sensor_manager_has_remote(uint32_t* ageMs) {
    if (ageMs) *ageMs = s_has_remote ? (millis() - s_remote_last_ms) : 0;
    return s_has_remote;
}

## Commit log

2026-09-01 chore: 初始化项目骨架（双固件工程 + 分层目录 + 调试开关）
2026-09-05 chore: 整理目录结构（firmware/docs/hardware/bin 分类 + 预留空位目录）
2026-09-06 feat: 双板固件框架 v0.1（腕端+腰端全模块，ESP-NOW联调通过）
    腕端：50Hz采集/OLED/交互按钮/ESP-NOW发送
    腰端：采集融合/报警状态机/取消按钮/推送占位
    MPU裸寄存器驱动兼容6050/6500；算法接口预留；I2C扫描工具
2026-09-07 feat: 微信推送全链路打通 v0.2（WxPusher + WiFi/ESP-NOW 共存恢复）
    腰端：net_pusher 队列+独立低优先级任务推送，推送后恢复 ESP-NOW 信道；secrets.h.example 模板（多 UID、文案可配置）
    腕端：交互按钮迁移 D1->D2/GPIO3（D1 焊盘虚焊），版本号 v0.2
    工具：wifi_test v2（disconnect reason 码诊断）、btn_test（全 GPIO 扫描定位按钮）
    实测：模拟跌倒->10s 取消窗口->WiFi 连接->WxPusher code=1000 推送成功->断流自恢复
2026-09-10 feat: 跌倒判定算法全链路 v0.3（离线训练->上板部署->腕端融合预留）
    algo/: SisFall数据管线（加载/特征/训练/阈值基线/森林导出），按人划分留出集灵敏96.0%特异98.4%，老年组压力测试误报3.0%、SE06真摔检出85%；量程裁剪域对齐(±8g/±500°/s)修复上板失效隐患
    腰端: fall_detector三阶段触发+15树随机森林（rf_model.h自动生成，双语言回放5920样本0不一致）；腕端融合v1否决票默认关闭（fail-open），decision日志增加wrist峰值/覆盖率
    推送: 常连模式PUSH_ALWAYS_ON（同信道共存）+失败重试6次不再丢弃+信道失配告警
    信道: 两端ESPNOW_CHANNEL 1->6匹配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
    [config.h]
2026-09-11 feat: CNN 二级仲裁 v2 —— 训练管线修复 + 影子模式（v0.4）
    训练侧（板端实现零改动，归一化口径不变）：
    - cnn_train.py v2：按受试者划分（修窗口泄漏）/ 峰值锚定标签（修 trial 级
    标签语义）/ 腕端缺失增广 + 腰腕独立随机旋转增广（对齐部署域）/ ablation
    - cnn_weights.h：v2 旋转版重新导出（真实指标 sens 70~78% / spec 98~99.8%，
    任意佩戴朝向稳定；对照实验证明无旋转版轴变后 spec 崩至 77.7%）
    - 新增 inspect_data.py：pkl 数据体检（标度/SMOTE/腕陀螺来源，全部通过）
    固件侧：
    - config.h CNN_ROLE_RESCUE 1->0：影子模式。RF 独自主判，CNN 只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
    [config.h]
2026-09-15 feat: 硬件集成 v0.5 —— 腕端状态LED + 腰端有源蜂鸣器两段式报警 + 编码器取消
    腕端：新增 hw_led 模块（心跳/链路故障/MPU离线三态闪烁），固件升 v0.5；PCB bring-up 通过（MPU/按钮/电池链路）
    腰端：蜂鸣器改有源驱动 digitalWrite（tone 方案作废），两段式报警音（取消窗急促哔哔→推送后长鸣）
    硬件：EC11 编码器按压脚替代取消按钮（电路等效零代码）；已知项：OLED 损坏待换、SW2 虚焊已 P4 锡桥旁路
    文档：新增 docs/handover_2026-09-14_hw_integration.md（接线表/交互规则/调参指南/改GPIO规则）；README 同步当前状态
2026-09-16 feat: 推送改为按需模式 + 取消窗缩至7s（应对热点信道漂移）
2026-09-22 docs: v0.5 按需推送联调交接文档（含演示脚本，09-16）
2026-09-22 feat: 推送文案规范化（类型前缀+取消窗说明+行动指引）
2026-09-22 feat: v0.6 报警状态回显腰->腕(PKT_ACK) + 腕端产品化UI（弹窗/取消倒计时/已取消页，DEBUG_DISPLAY开关，长按2s防误触）
2026-09-22 feat: v0.6 腕端时钟显示（腰端开机一次性NTP，epoch经PKT_ACK下发，本地走时）+ 正常页STEPS预留行 + 长按回1s
2026-09-22 feat: NTP同步提速（开机8s+成功立即下发+失败重试3次）+ 报警期间自动避让射频
2026-09-22 fix: WiFi重试卡死修复（超时/begin前disconnect清残留，根因 sta is connecting cannot set config）
2026-09-22 chore: 暂关NTP同步（排查推送热点问题）+ 推送失败自动扫描诊断（AP是否在2.4G广播/信道/加密）
2026-09-22 diag: 推送失败扫描列出全部AP（区分热点未广播 vs 射频扫描异常）
2026-09-22 revert: 移除NTP时间同步功能（实现保留于git历史 d337728~1c87b4f，恢复可cherry-pick）；保留WiFi重试修复与失败扫描诊断
2026-09-22 feat: v0.6 腕端步数统计（纯本地SVM峰值检测+RAM计数，零通信改动，点亮OLED的STEPS行）
2026-09-22 fix: 步数防误报（阈值2.5m/s2 + 连续4步确认补记，孤立晃动不计数）
    [config.h]
2026-09-22 fix: 步数阈值回落2.0（2.5挡住正常走路，防误报已由连续步确认承担）
2026-09-22 docs: v0.6 交接文档 + README 更新（当前状态/架构表OLED位置纠正）
2026-09-22 hardware: 腕端PCB原理图PDF/Gerber/EDA工程源文件 + 3D外壳STL入库（决赛提交材料）
    [腕端最终.stl]
2026-09-27 fix: 蜂鸣器7秒后停响——回显发送移出task_alarm到独立低优先级任务，ST_SENT期不再重发（根因：推送连WiFi期间esp_now_send阻塞alarm_tick）
2026-09-30 docs: 交付前表述清理——README 更新为最终版状态
2026-09-30 格式整理
2026-09-30 chore: 格式整理
